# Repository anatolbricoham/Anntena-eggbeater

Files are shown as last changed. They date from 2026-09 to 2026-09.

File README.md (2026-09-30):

# Eggbeater II de K5OE (2 m y 70 cm) con piezas impresas en 3D

Es la **Eggbeater II de Jerry Brown, K5OE**, la antena omnidireccional con polarización circular que diseñó para satélites LEO. Se reproduce **con sus medidas originales**. Lo único añadido son las piezas de plástico impresas en 3D que sustituyen a los accesorios de PVC y a los taladros hechos a ojo. No se ha cambiado ninguna medida eléctrica.

| | 2 m | 70 cm |
|---|---|---|
| Lazos (ancho × alto, entre ejes) | **51 × 63 cm** | **17.1 × 20.9 cm** |
| Conductor | Hilo de cobre #8 AWG (3.26 mm) | Igual, o varilla de 3 mm |
| Reflectores (2 varillas de Al de 1/4" cruzadas) | **100.5 cm**, a **101 cm** bajo los lazos | **33.5 cm**, a **33 cm** bajo los lazos |
| Línea de fase RG-62 (93 Ω) | **41.5 cm** con malla (se corta a 46.5 cm y se pelan 2.5 cm por extremo) | **13.5 cm** (se corta a 18.5 cm y se pelan 2.5 cm por extremo) |
| Alimentación | Tapón en la punta del mástil; los lados inferiores atraviesan el tubo | Igual |
| Polarización | RHCP (LHCP cruzando la línea de fase en B) | RHCP |

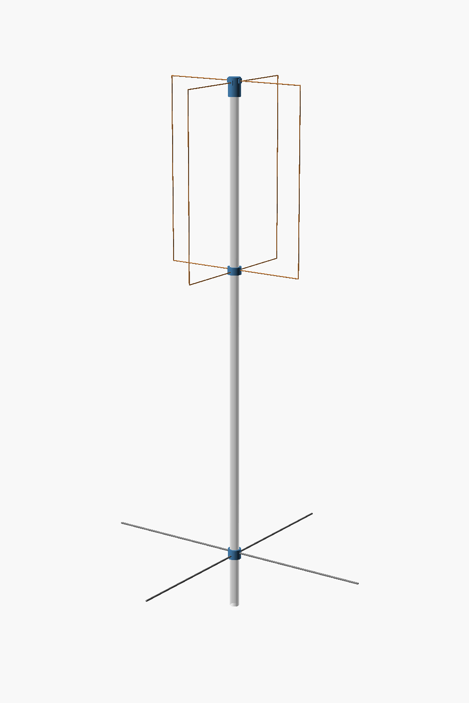
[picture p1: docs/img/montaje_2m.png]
Montaje 2 m


## Verificación por simulación (NEC2)
Se modeló la geometría de K5OE **tal cual** en `sim/k5oe.py`, con nec2c. No se optimizó nada.

| | Z entrada | ROE en la sub-banda de satélite | ROE < 1.5 | RHCP a 10° / 30° / 60° / 90° de elevación |
|---|---|---|---|---|
| 2 m (145.9 MHz) | 46.3 − j1.3 Ω | **1.08** | 136–151 MHz | +0.3 / −0.7 / −3.1 / −2.5 dBic |
| 70 cm (436.5 MHz) | 51.2 − j0.5 Ω | **1.00–1.05** | 419–463 MHz | +0.1 / −0.8 / −3.2 / −2.8 dBic |

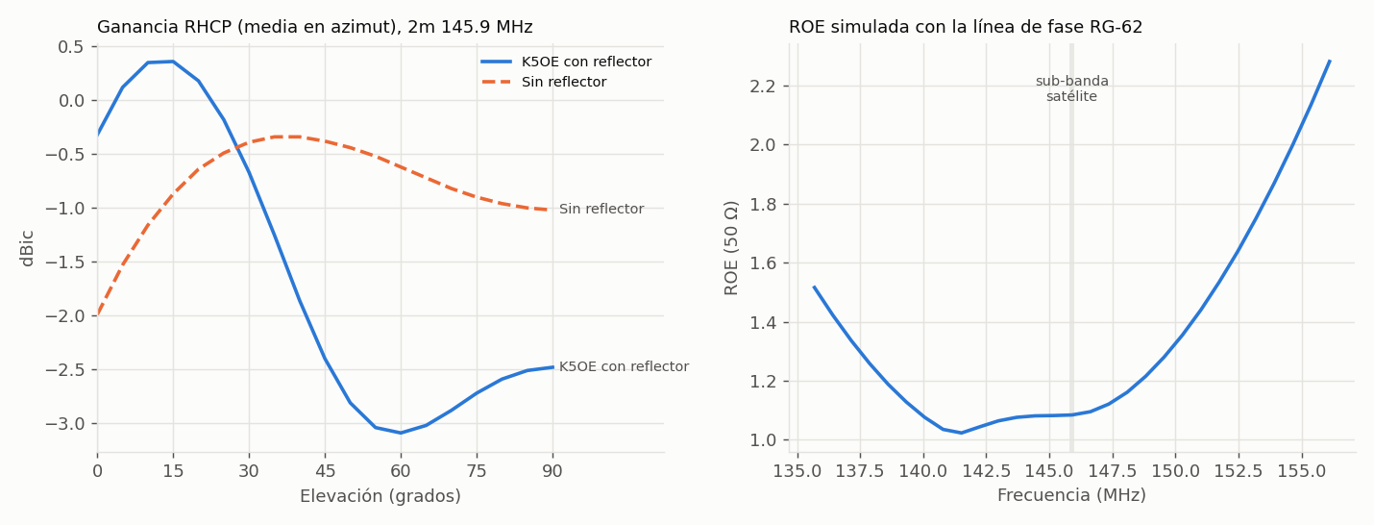
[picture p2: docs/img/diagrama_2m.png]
2 m

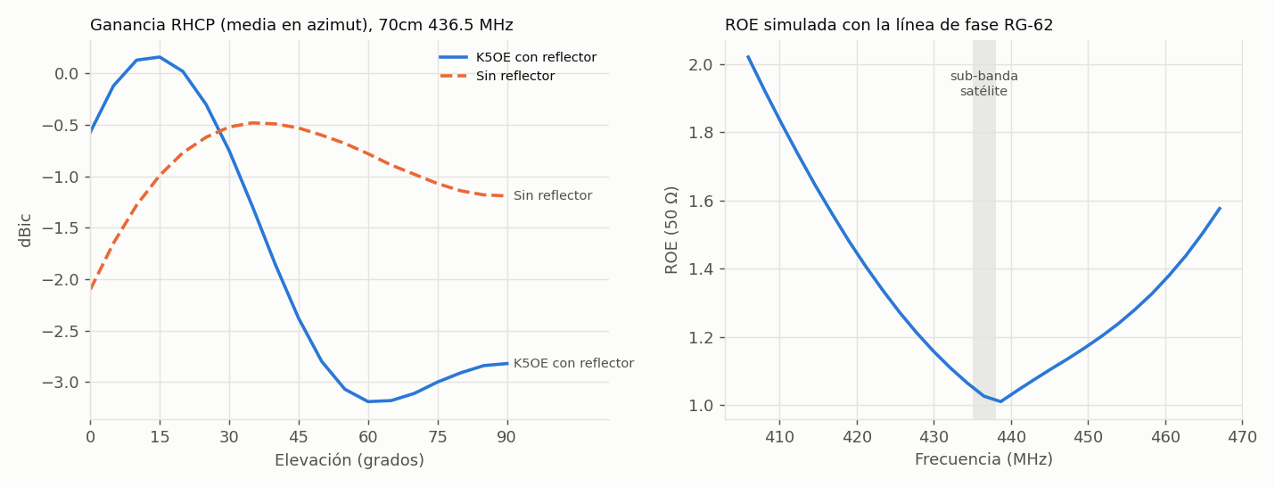
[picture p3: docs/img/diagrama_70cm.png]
70 cm


Con el reflector a ~½ λ, K5OE concentra la ganancia en los ángulos bajos (0–30°). Ahí es donde el satélite está más lejos y donde pasa más tiempo, y es la razón de ser de su diseño.

## Piezas impresas (`stl/`)

| Pieza | Función |
|---|---|
| `tapon_<banda>` | Tapón de alimentación en la punta del tubo. Lleva los 4 bornes rotulados A+, A−, B+ y B− (tornillos de latón M6 en 2 m, M5 en 70 cm), con el lazo B 6 mm más bajo que el A. Dentro tiene una cámara para tuercas, terminales y línea de fase, y el coaxial sube por dentro del tubo. Se imprime boca abajo |
| `guia_lazos_<banda>` | Collarín a la altura de los lados inferiores. Sirve de **guía para taladrar** el tubo en cruz y a dos alturas, y luego sujeta los hilos con prisioneros |
| `guia_reflector_<banda>` | Lo mismo para las dos varillas del reflector (1/4") |
| `plantilla_70cm` | Plantilla de 171 × 209 mm para doblar y comprobar el lazo de 70 cm (el de 2 m no cabe en una impresora) |

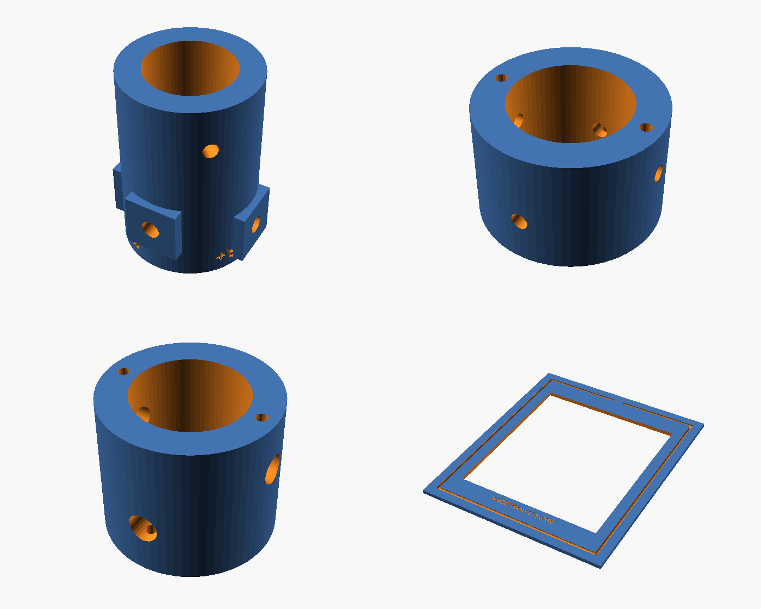
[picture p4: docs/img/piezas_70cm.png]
Piezas 70 cm


Cómo imprimirlas:
- **Material:** **ASA** o **PETG** (nada de PLA en exterior).
- **Parámetros:** 0.2 mm de capa, 4 perímetros, 40 % de relleno.
- **Soportes:** no hacen falta.

## Material (una antena)

| | 2 m | 70 cm |
|---|---|---|
| Lazos | 2 × 2.25 m de hilo de Cu #8 AWG (se usan 2234 mm) | 2 × 0.75 m de hilo #8 o de varilla de 3 mm (se usan 718 mm) |
| Reflector | 2 varillas de Al Ø1/4" de 1005 mm | 2 de 335 mm |
| Línea de fase | 46.5 cm de RG-62 | 18.5 cm de RG-62 |
| Mástil | Tubo de PVC Ø32 de 2 m | Tubo de PVC Ø25 de 0.8 m |
| Bornes | 4 tornillos M6×16 de latón, 8 tuercas, 8 arandelas, 4 terminales de ojal | 4 tornillos M5×12 de latón, etc. |
| Otros | 3 autorroscantes de 4.2 mm, 8 autorroscantes M3, coaxial de 50 Ω, choque de RF, cinta autovulcanizante | Igual |

Guías: [construcción](docs/CONSTRUCCION.md), [K5OE y fuentes](docs/TEORIA.md) y [pruebas](docs/PRUEBAS.md).

## Estructura
```
cad/eggbeater_k5oe.scad   Piezas paramétricas (BAND = "2m" | "70cm"; PART = tapon | guia_lazos | guia_reflector | plantilla | montaje)
stl/                      STL listos para imprimir
sim/                      Modelo NEC2 de la geometría K5OE (eggbeater.py, k5oe.py), resultados y mazos .nec
scripts/build.sh          Regenera STL, renders y gráficas
docs/                     Construcción, teoría, pruebas e imágenes
```
`make` regenera las piezas y las gráficas. `make sim` repite la simulación NEC2 (necesita `nec2c`).

## Créditos
Diseño eléctrico: **Jerry Brown, K5OE**, *Eggbeater II Omni LEO Antenna*. Las piezas impresas y la verificación NEC2 son de este repositorio.

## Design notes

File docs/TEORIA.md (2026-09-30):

# La Eggbeater II de K5OE

## Diseño
Jerry Brown, K5OE, publicó la *Eggbeater II Omni LEO Antenna* como antena fija, sin rotor, para satélites de órbita baja:
- **Lazos:** dos rectangulares de ~1.1 λ de perímetro, en proporción 45:55 entre lado horizontal y vertical, cruzados a 90° sobre un tubo de PVC.
- **Alimentación:** **en la parte superior**, en un tapón del tubo. Los lados inferiores atraviesan el mástil.
- **Impedancia:** cada lazo de onda completa presenta ~100 Ω; en paralelo dan ~50 Ω. No hace falta adaptador.
- **Línea de fase:** un tramo de **RG-62 (93 Ω)** de ~λ/4 eléctrico entre los dos lazos. Da los 90° de desfase y, con ello, la polarización circular.
- **Reflector:** dos varillas cruzadas de ~½ λ, a ~½ λ por debajo. Refuerzan la radiación hacia el horizonte (0–30°), donde el satélite está más lejos y pasa más tiempo.

Fórmulas de los lazos (f en MHz), recogidas por parker-research a partir de K5OE: **lado horizontal = 7464.8 / f cm** y **lado vertical = 9123.6 / f cm**. Dan 51.2 × 62.5 cm a 145.9 MHz y 17.1 × 20.9 cm a 436.5 MHz, de acuerdo con las medidas publicadas.

## Medidas originales y de dónde salen
No se pudo acceder a la página original de K5OE (wb5rmg.somenet.net) porque redirige en bucle. Las medidas proceden de reconstrucciones que citan su artículo y coinciden entre sí:

| Dato | 2 m | 70 cm | Fuente |
|---|---|---|---|
| Lazos | 51 × 63 cm | 17 × 21 cm (17.1 × 20.9) | ZR6AIC; ZS Link; parker-research |
| Reflectores | 100.5 cm a 101 cm | 33.5 cm a 33 cm | ZR6AIC; ZS Link |
| Línea de fase RG-62 | 41.5 cm | 13.5 cm (cortar 18.5 y pelar 2.5 + 2.5) | ZR6AIC; ZS Link |
| Hilo | #8 AWG | #8 AWG / 3 mm | ZR6AIC; ZS Link |
| Estructura | Tapón con 4 tornillos de latón en la punta del tubo; tubo de PVC | Igual | ZS Link; Libre Space |

## Verificación NEC2
En `sim/k5oe.py` se modela la geometría de K5OE sin tocarla:
- lazos alimentados arriba, con el lazo B 6 mm más bajo;
- hilo de 3.26 mm y reflectores de 1/4";
- la línea de fase como línea de transmisión de 93 Ω con VF 0.84, más 2.5 cm de colas por extremo.

Resultados:
- **Adaptación:** 46 Ω a 145.9 MHz y 51 Ω a 436.5 MHz. ROE ≤ 1.08 en las sub-bandas de satélite.
- **Ancho de banda (ROE < 1.5):** 136–151 MHz y 419–463 MHz. Es muy tolerante a errores de construcción.
- **Diagrama:** máximo de RHCP entre 5° y 25° de elevación (≈ 0 dBic) y unos −2.5/−3 dBic en el cenit. La LHCP queda más de 13 dB por debajo en el cenit.

**Nota sobre 70 cm.** Algunos constructores dicen que su versión de 70 cm resonaba alto (~465 MHz) y recomiendan hacerla un 7 % mayor y recortar. La simulación de las medidas originales **no** muestra ese desplazamiento. Lo más probable es que se deba a esquinas redondeadas, hilos más gruesos o colas largas. Mide y ajusta antes de recortar (ver PRUEBAS).

## Fuentes
- K5OE, *Eggbeater II Omni LEO Antenna*: http://wb5rmg.somenet.net/k5oe/Eggbeater_2.html (original, no accesible desde aquí)
- ZR6AIC, [Building my Eggbeater II Omni LEO Antennas](https://zr6aic.blogspot.com/2013/03/building-my-eggbeater-ii-omni-leo.html)
- ZS Link Network, [The Eggbeater II satellite antenna](https://grhubnetwork.blogspot.com/2022/05/the-eggbeater-ii-satellite-antenna.html)
- parker-research, [Eggbeater-Antenna-PCB (fórmulas K5OE)](https://github.com/parker-research/Eggbeater-Antenna-PCB)
- Libre Space Community, [Home made Eggbeater antenna](https://community.libre.space/t/home-made-eggbeater-antenna/2652)
- Pete Brunelli, [The Well Tuned Eggbeater](https://petebrunelli.com/2022/09/16/the-well-tuned-eggbeater/)

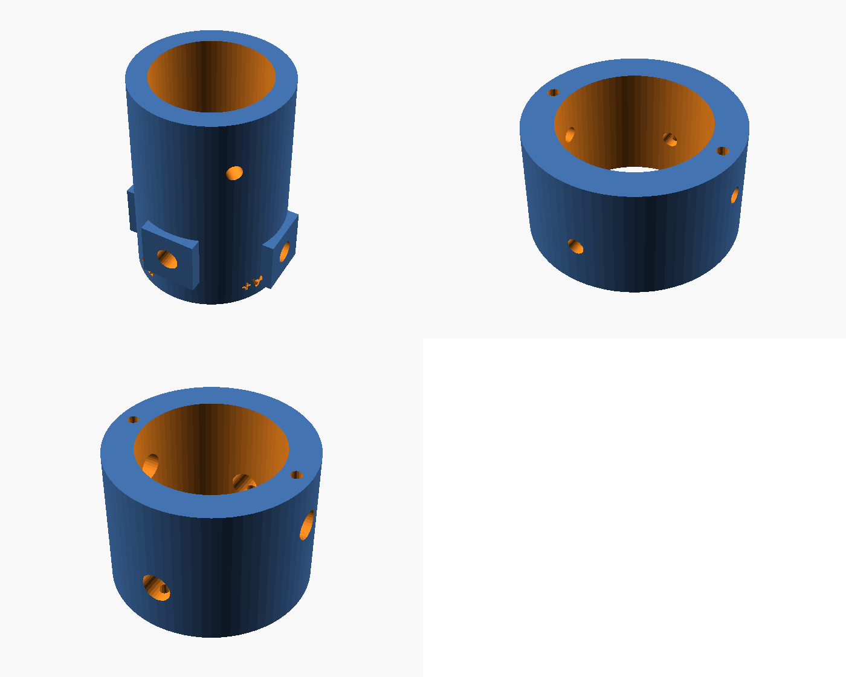
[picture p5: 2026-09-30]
docs/img/piezas_2m.png

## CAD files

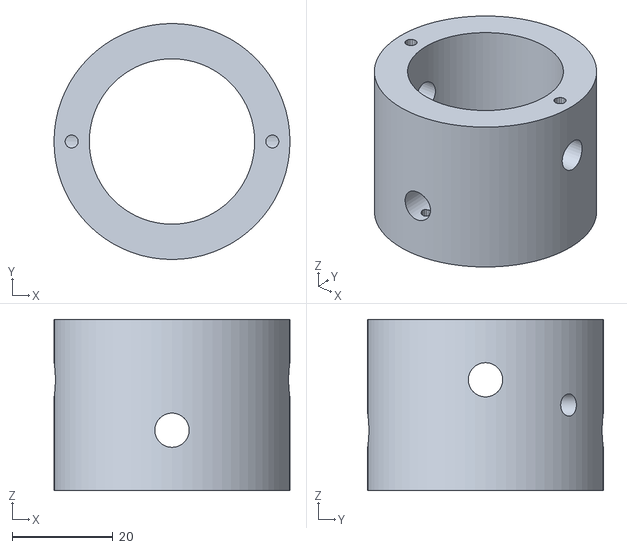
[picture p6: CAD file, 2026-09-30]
stl/guia_reflector_2m.stl
46.8 x 46.8 x 34.0

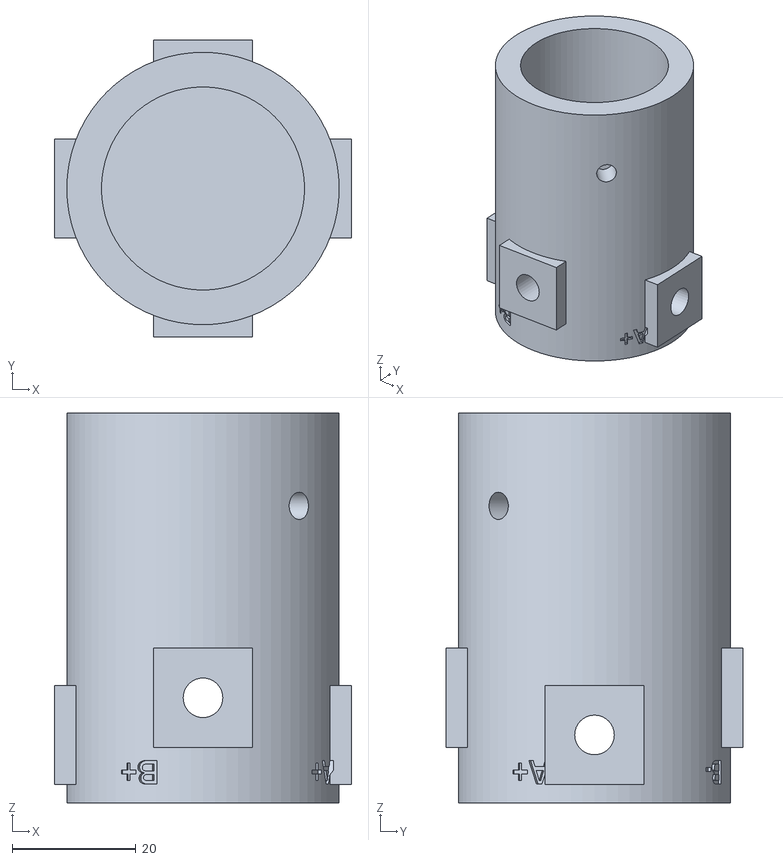
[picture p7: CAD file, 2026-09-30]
stl/tapon_2m.stl
48.0 x 48.0 x 63.0

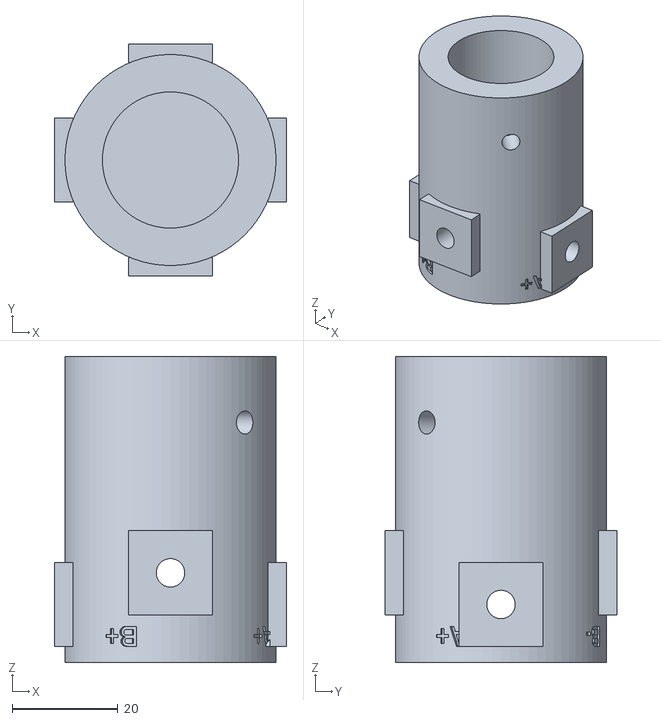
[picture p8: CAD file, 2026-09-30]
stl/tapon_70cm.stl
44.0 x 44.0 x 58.0

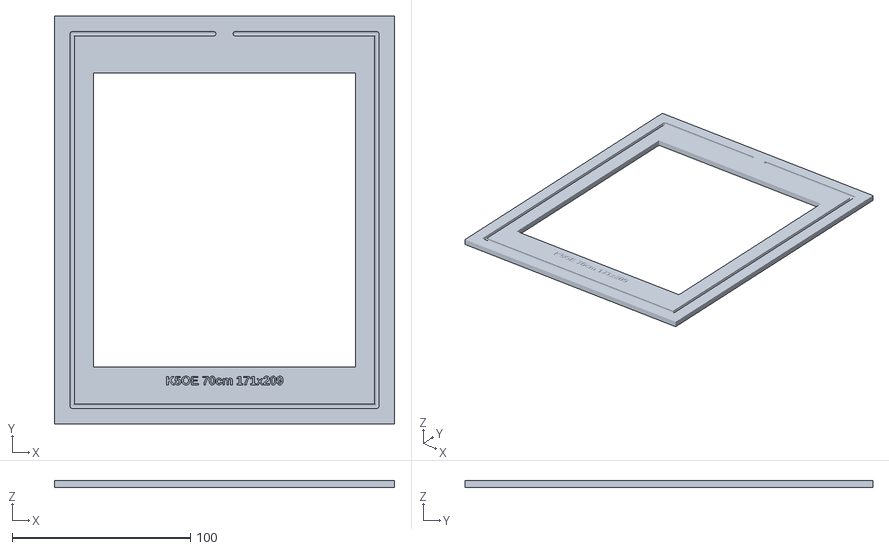
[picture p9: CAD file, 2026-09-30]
stl/plantilla_70cm.stl
191.0 x 229.0 x 4.00

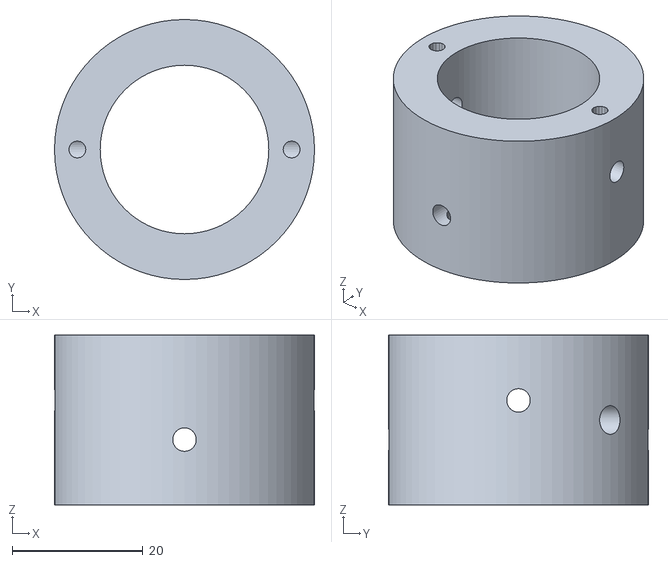
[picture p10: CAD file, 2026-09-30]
stl/guia_lazos_70cm.stl
39.8 x 39.8 x 26.0

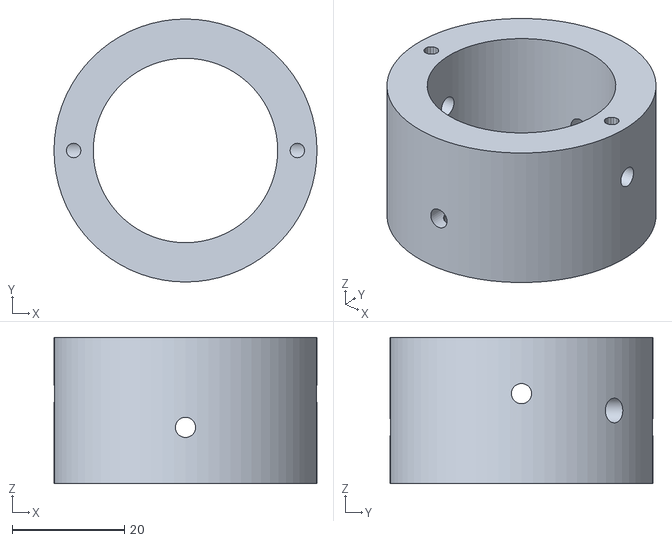
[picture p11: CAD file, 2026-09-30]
stl/guia_lazos_2m.stl
46.8 x 46.8 x 26.0

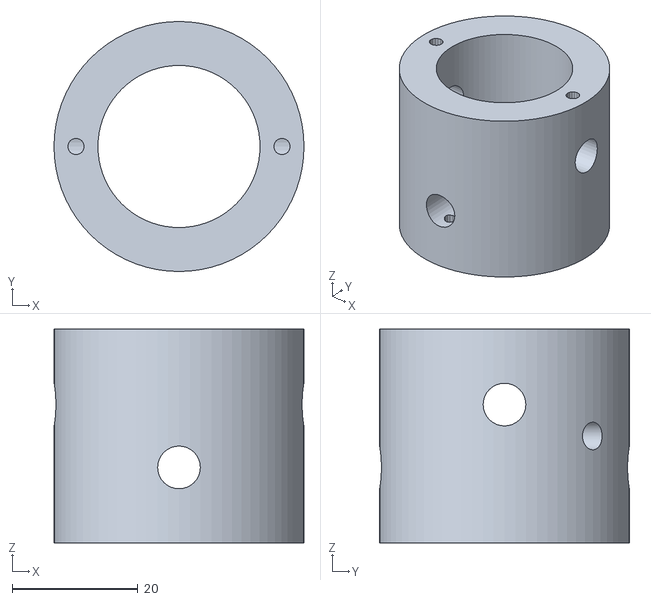
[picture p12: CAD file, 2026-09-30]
stl/guia_reflector_70cm.stl
39.8 x 39.8 x 34.0

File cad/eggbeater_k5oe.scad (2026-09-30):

// =====================================================================
//  Eggbeater II de K5OE: piezas imprimibles (2 m y 70 cm)
//  Geometria ORIGINAL de K5OE: lazos rectangulares alimentados ARRIBA en el tapon
//  del mastil, lados inferiores atravesando el mastil, 2 reflectores cruzados debajo.
//
//  openscad -D 'BAND="2m"' -D 'PART="tapon"' -o tapon.stl eggbeater_k5oe.scad
//    BAND = "2m" | "70cm"
//    PART = "tapon" | "guia_lazos" | "guia_reflector" | "plantilla" (solo 70 cm) | "montaje"
//  Unidades: mm. Imprimir en ASA o PETG, 4 perimetros, 40 % de relleno.
// =====================================================================
BAND = "2m";
PART = "montaje";
$fn = 72;
IS2 = BAND == "2m";

// ---------------- medidas de K5OE (no cambiar) ----------------
LOOP_W = IS2 ? 510 : 171;       // ancho del lazo (entre ejes del hilo)
LOOP_H = IS2 ? 630 : 209;       // alto del lazo
REFL_L = IS2 ? 1005 : 335;      // longitud de cada reflector
REFL_D = IS2 ? 1010 : 330;      // distancia bajo los lados inferiores de los lazos
PHASE  = IS2 ? 415 : 135;       // RG-62 con malla (se cortan 50 mm mas: 25 mm pelados por extremo)

// ---------------- mecanica (ajustable) ----------------
MAST_D = IS2 ? 32 : 25;         // tubo de PVC (K5OE: PVC de 1")
CLR    = 0.4;
WIRE   = 3.3;                   // hilo de cobre #8 AWG (3.26 mm) o varilla de 3 mm
ROD    = 6.5;                   // reflectores: varilla de aluminio de 1/4" (6.35 mm)
DZ     = 6;                     // desnivel entre lazo A y lazo B (el B va 6 mm mas bajo)
BOLT   = IS2 ? 6 : 5;           // tornillo de laton de los bornes (M6 / M5)

MR = MAST_D / 2 + CLR;

// ------------------------------------------------ TAPON DE ALIMENTACION
CH_D   = IS2 ? 36 : 32;         // camara interior (tuercas, terminales, linea de fase)
CAP_W  = 4;
SOCK   = IS2 ? 30 : 25;         // encaje sobre el tubo
CH_H   = 30;
CAP_OD = max(CH_D, 2 * MR) + 2 * CAP_W;
Z_BA   = SOCK + CH_H - 8;       // nivel de los bornes del lazo A
Z_BB   = Z_BA - DZ;             // nivel de los bornes del lazo B
CAP_H  = SOCK + CH_H + 3;
BORNES = [[0, Z_BA], [90, Z_BB], [180, Z_BA], [270, Z_BB]];
module tapon() {
    difference() {
        union() {
            cylinder(d = CAP_OD, h = CAP_H);
            for (t = BORNES)   // asiento plano para la cabeza de cada tornillo
                rotate(t[0]) translate([CAP_OD / 2 - 1.5, -8, t[1] - 8]) cube([3.5, 16, 16]);
        }
        translate([0, 0, -1]) cylinder(r = MR, h = SOCK + 1);                   // encaje del tubo
        translate([0, 0, SOCK - 0.01]) cylinder(d = CH_D, h = CH_H);             // camara
        for (t = BORNES)
            rotate(t[0]) translate([0, 0, t[1]]) rotate([0, 90, 0]) cylinder(d = BOLT + 0.4, h = CAP_OD, $fn = 32);
        // rotulos en el lateral (vista desde arriba: B+ 90 grados antihorario desde A+ -> RHCP)
        for (t = [[0, "A+"], [180, "A-"], [90, "B+"], [270, "B-"]])
            rotate(t[0] + 28) translate([CAP_OD / 2 - 0.6, 0, CAP_H - 5]) rotate([90, 0, 90])
                linear_extrude(1) text(t[1], size = 4, halign = "center", valign = "center",
                                       font = "Liberation Sans:style=Bold");
        rotate(45) translate([MR, 0, SOCK / 2]) rotate([0, 90, 0]) cylinder(d = 4.4, h = 20, center = true);
    }
}

// ------------------------------------------------ COLLARINES (guia de taladro + sujecion)
module collarin(hole, sep, h) {
    difference() {
        cylinder(r = MR + 7, h = h);
        translate([0, 0, -1]) cylinder(r = MR, h = h + 2);
        // dos pasos cruzados: el de arriba (lazo A / reflector 1) en el eje X
        translate([0, 0, h / 2 + sep / 2]) rotate([0, 90, 0]) cylinder(d = hole, h = 4 * MR + 30, center = true, $fn = 32);
        translate([0, 0, h / 2 - sep / 2]) rotate([90, 0, 0]) cylinder(d = hole, h = 4 * MR + 30, center = true, $fn = 32);
        // prisioneros M3 autorroscantes
        for (a = [0, 180]) rotate(a) translate([MR + 3.5, 0, h / 2 + sep / 2]) cylinder(d = 2.6, h = h, $fn = 16);
        for (a = [90, 270]) rotate(a) translate([MR + 3.5, 0, -1]) cylinder(d = 2.6, h = h / 2 - sep / 2 + 1, $fn = 16);
        rotate(45) translate([MR + 3.5, 0, h / 2]) rotate([0, 90, 0]) cylinder(d = 4.4, h = 20, center = true);
    }
}
module guia_lazos()     collarin(WIRE + 0.3, DZ, 26);
module guia_reflector() collarin(ROD + 0.3, 10, 34);

// ------------------------------------------------ PLANTILLA DE DOBLADO (70 cm)
module plantilla() {
    m = 10; t = 4; W = LOOP_W; H = LOOP_H;
    difference() {
        translate([-W / 2 - m, -m, 0]) cube([W + 2 * m, H + 2 * m, t]);
        for (s = [[[-W / 2, 0], [W / 2, 0]], [[W / 2, 0], [W / 2, H]], [[-W / 2, 0], [-W / 2, H]],
                  [[-W / 2, H], [-6, H]], [[6, H], [W / 2, H]]])
            hull() for (p = s) translate([p[0], p[1], t - WIRE / 2 + 0.3]) sphere(d = WIRE + 0.4, $fn = 16);
        translate([-W / 2 + 12, 22, -1]) cube([W - 24, H - 44, t + 2]);    // aligerado
        translate([0, 12, t - 0.6]) linear_extrude(1)
            text(str("K5OE 70cm ", W, "x", H), size = 5, halign = "center", font = "Liberation Sans:style=Bold");
    }
}

// ------------------------------------------------ VISTA DE MONTAJE
module w(a, b, d = WIRE) hull() { translate(a) sphere(d = d, $fn = 10); translate(b) sphere(d = d, $fn = 10); }
GL_H = 26; GR_H = 34;
module montaje() {
    zA = Z_BA; zB = Z_BB; x0 = CAP_OD / 2 + 2; ww = LOOP_W / 2;
    color("white", 0.6) translate([0, 0, zA - LOOP_H - REFL_D - 200]) cylinder(d = MAST_D, h = SOCK - (zA - LOOP_H - REFL_D - 200));
    color("SteelBlue") tapon();
    color("SteelBlue") translate([0, 0, zA - LOOP_H - GL_H / 2 - DZ / 2]) guia_lazos();
    color("SteelBlue") translate([0, 0, zA - LOOP_H - REFL_D - GR_H / 2 - 5]) guia_reflector();
    color("#b87333") {
        for (s = [-1, 1]) w([s * x0, 0, zA], [s * ww, 0, zA]);
        for (s = [-1, 1]) w([s * ww, 0, zA], [s * ww, 0, zA - LOOP_H]);
        w([-ww, 0, zA - LOOP_H], [ww, 0, zA - LOOP_H]);
        for (s = [-1, 1]) w([0, s * x0, zB], [0, s * ww, zB]);
        for (s = [-1, 1]) w([0, s * ww, zB], [0, s * ww, zB - LOOP_H]);
        w([0, -ww, zB - LOOP_H], [0, ww, zB - LOOP_H]);
    }
    color("gray") {
        w([-REFL_L / 2, 0, zA - LOOP_H - REFL_D], [REFL_L / 2, 0, zA - LOOP_H - REFL_D], ROD);
        w([0, -REFL_L / 2, zA - LOOP_H - REFL_D - 10], [0, REFL_L / 2, zA - LOOP_H - REFL_D - 10], ROD);
    }
}

if (PART == "tapon") translate([0, 0, CAP_H]) rotate([180, 0, 0]) tapon();   // imprimir boca abajo
else if (PART == "guia_lazos") guia_lazos();
else if (PART == "guia_reflector") guia_reflector();
else if (PART == "plantilla") plantilla();
else montaje();
echo(str("K5OE ", BAND, ": tapon D", CAP_OD, " x ", CAP_H, " mm; bornes a ", Z_BA, " mm del borde inferior del tapon;",
         " lazos: ", 2 * LOOP_H + 2 * LOOP_W, " mm de perimetro"));

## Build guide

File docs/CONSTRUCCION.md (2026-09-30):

# Construcción (según K5OE)

## 1. Preparar el mástil
- **Tubo:** de PVC, Ø32 para 2 m y Ø25 para 70 cm. Las medidas se toman **desde la punta del tubo**, que queda dentro del tapón:

| Taladro (en cruz, con el collarín como guía) | 2 m | 70 cm |
|---|---|---|
| Lado inferior del lazo A | 608 mm | 187 mm |
| Lado inferior del lazo B (6 mm más abajo, a 90°) | 614 mm | 193 mm |
| Reflector 1 | 1618 mm | 517 mm |
| Reflector 2 (10 mm más abajo, a 90°) | 1628 mm | 527 mm |

- **Cómo taladrar:** pon cada collarín en su sitio, fíjalo con su autorroscante y taladra el tubo a través de sus agujeros: Ø3.5 para el hilo y Ø6.5 para el reflector.
- **Longitud total:** deja 30 cm de tubo bajo el reflector para amarrar la antena al mástil. En la zona de la antena no debe haber metal.

## 2. Lazos: pasar el hilo por el tubo y doblar
Cada lazo sale de un solo hilo. Marcas desde un extremo, entre ejes. Los 5 mm de cada punta van dentro de la cabeza del tornillo del borne.

| Tramo | 2 m | 70 cm |
|---|---|---|
| Medio lado superior (de la cabeza del tornillo a la esquina, +5 mm dentro de la cabeza) | 232 mm | 64.5 mm |
| Lateral | 630 mm | 209 mm |
| Lado inferior (atraviesa el tubo) | 510 mm | 171 mm |
| Lateral | 630 mm | 209 mm |
| Medio lado superior | 232 mm | 64.5 mm |
| **Total** | **2234 mm** | **718 mm** |

1. **Pasar el hilo:** mete el hilo **recto** por los dos taladros del lazo A y céntralo.
2. **Esquinas inferiores:** dobla las dos a 90° hacia arriba.
3. **Esquinas superiores:** dóblalas hacia el centro. En 70 cm usa la `plantilla_70cm` como referencia.
4. **Lazo B:** repite con el B, 90° girado y 6 mm más abajo.
5. **Fijar:** aprieta los prisioneros del collarín para que los hilos no giren.

## 3. Tapón y bornes (como K5OE)
1. **Tornillos:** taladra la cabeza de cada tornillo de latón (Ø3.5, unos 5 mm de profundidad), mete el extremo del hilo y suéldalo. Esto se hace en el tapón o antes de montarlo.
2. **Coaxial de bajada:** sube el coaxial de 50 Ω por dentro del tubo hasta la cámara del tapón.
3. **Línea de fase RG-62:** en 2 m, córtala a 46.5 cm y pela 2.5 cm en cada extremo, para que queden 41.5 cm con malla. En 70 cm, 18.5 → 13.5 cm. Pon terminales de ojal en vivos y mallas.
4. **Conexiones dentro de la cámara:** tuerca, terminal y contratuerca en cada tornillo:

```
Vista desde arriba          B+ (tornillo en +Y, 6 mm más bajo)
                             |
          A- (−X) ----- [tapón] ----- A+ (+X)
                             |
                            B-
Coaxial de bajada:  vivo -> A+     malla -> A-
Línea de fase RG-62: vivo A+ -> B+   malla A- -> B-      => RHCP
(para LHCP: en el extremo B, vivo -> B- y malla -> B+)
```

5. **Cerrar:** empuja el tapón sobre el tubo (el sobrante de la línea de fase queda dentro del tubo) y fíjalo con el autorroscante de 4.2 mm. Sella los tornillos por fuera con silicona neutra o autovulcanizante.

## 4. Reflectores
Pasa las dos varillas por el collarín y el tubo, céntralas y fíjalas con los prisioneros. Quedan aisladas, igual que en el original.

## 5. Instalación
- **Choque de RF:** justo debajo del reflector. En 2 m, 5–6 espiras de coaxial de Ø10 cm; en 70 cm, 4 espiras de Ø5 cm. También valen ferritas de mezcla 43/61.
- **Emplazamiento:** lo más alto y despejado posible. Separa la antena de 2 m y la de 70 cm al menos 1 m.
- **Preamplificador:** para recepción, un LNA en el mástil (sobre todo en 70 cm).

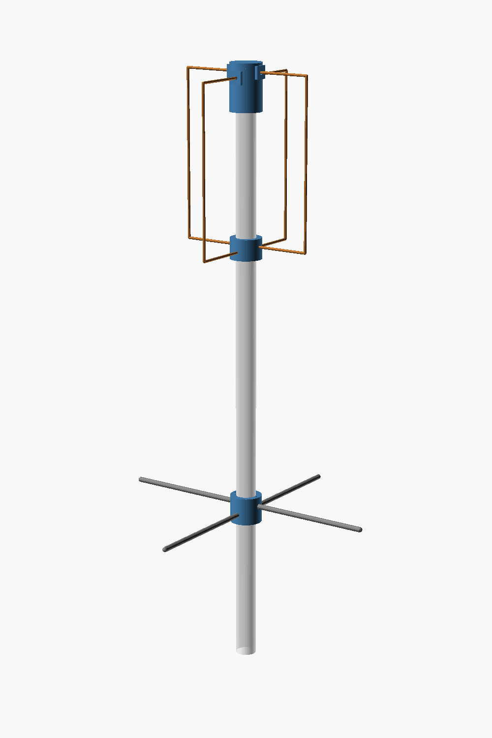
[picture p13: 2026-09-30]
docs/img/montaje_70cm.png

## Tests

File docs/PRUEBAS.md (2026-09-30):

# Ajuste y pruebas

## 1. Antes de medir
- **Continuidad:** entre el vivo y la malla del conector debe haber **continuidad en DC**, porque cada lazo es una espira cerrada.
- **Aislamiento:** los lazos A y B no se tocan entre sí y los reflectores no tocan los lazos.
- **Cableado de la fase:** A+→B+ y A−→B− para RHCP.

## 2. ROE
1. **Montaje:** antena en su sitio, o a más de 3 m del suelo y lejos de metal. Mide al final de la bajada, con el choque puesto.
2. **Barrido:** 2 m de 135 a 155 MHz, 70 cm de 410 a 470 MHz.
3. **Esperado (simulación):** ROE ≤ 1.1 en 145.8–146.0 y 435–438 MHz, y < 1.5 en una banda muy ancha.
4. **Si el mínimo sale muy desplazado:**
   - Primero revisa las medidas (entre ejes), las esquinas y las colas de la línea de fase.
   - Después ajusta los laterales, igual en los dos lazos. En 2 m el perímetro cambia ~0.7 %/MHz, unos 4 mm por lateral; en 70 cm ~0.23 %/MHz, unos 0.5 mm por lateral.

## 3. Polarización
- **Con un walkie con antena vertical,** a distancia: gíralo de vertical a horizontal. La variación debe ser menor de 3 dB.
- **Sentido:** cruzar la línea de fase en B (LHCP) debe hacer caer la señal en el cenit de un satélite o de una fuente RHCP conocida.

## 4. Con satélites
1. **Pases:** predícelos con Gpredict, SatPC32 u Orbitron. Prueba con la ISS (145.800 FM), SO-50 (436.795), AO-91 y las balizas de cubesats en 435–438 MHz.
2. **Qué anotar:** la elevación a la que se engancha y se pierde la señal, y la S/N.
3. **Qué esperar:** con LNA, señal desde 5–10° en pases buenos. Por el diagrama de K5OE, la señal debe mantenerse bastante constante durante todo el pase.

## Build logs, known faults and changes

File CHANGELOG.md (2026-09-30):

# Cambios

## v2.0 (2026-09-30)
- **El proyecto se rehace sobre la Eggbeater II original de K5OE**, con sus medidas eléctricas sin modificar:
  - 2 m: 51 × 63 cm, reflector de 100.5 cm a 101 cm, RG-62 de 41.5 cm.
  - 70 cm: 17.1 × 20.9 cm, reflector de 33.5 cm a 33 cm, RG-62 de 13.5 cm.
- Piezas nuevas, con la arquitectura de K5OE (alimentación arriba y lados inferiores que atraviesan el tubo): tapón de alimentación, guía de lazos, guía del reflector y plantilla de 70 cm.
- Verificación NEC2 de la geometría original (`sim/k5oe.py`).
- Se retira la versión basada en EA5WA con reflector reoptimizado (v1.0, sigue en el historial de Git).

## v1.0
- Adaptación de la Eggbeater V2 de EA5WA con reflector optimizado (sustituida).

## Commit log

2026-09-30 Eggbeater para satelites 2 m / 70 cm con piezas impresas en 3D (v1.0)
    - Basada en la Eggbeater V2 de EA5WA (y K5OE Eggbeater II), reajustada a
    145.9 MHz y 436.5 MHz
    - Modelo NEC2 con optimizacion del reflector para margen de enlace LEO
    - Piezas OpenSCAD parametricas + STL (buje, tapa, tope, soporte reflector)
    - Documentacion: construccion, teoria con fuentes, pruebas
    Claude-Session: https://claude.ai/code/session_01U6JtTJmfWMf3hM8AetY1BM
    [buje_2m.stl, buje_70cm.stl, dimensiones.scad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]
2026-09-30 v2.0: rehecha sobre la Eggbeater II original de K5OE
    - Medidas electricas de K5OE sin modificar (2 m: 51x63 cm, reflector 100.5 cm
    a 101 cm, RG-62 41.5 cm; 70 cm: 17.1x20.9 cm, reflector 33.5 cm a 33 cm,
    RG-62 13.5 cm)
    - Piezas impresas con la arquitectura K5OE: tapon de alimentacion con bornes
    y camara, collarines guia de taladro (lazos y reflector), plantilla 70 cm
    - Verificacion NEC2 de la geometria original (sim/k5oe.py)
    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
    [buje_2m.stl, buje_70cm.stl, dimensiones.scad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]
